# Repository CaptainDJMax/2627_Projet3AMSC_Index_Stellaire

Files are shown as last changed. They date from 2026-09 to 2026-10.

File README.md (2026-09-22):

## Project Description
The "Stellar Index" is an autonomous and aesthetic mechanical arm, designed to point in real time at a specific celestial object selected via a mobile or web app. Whether it's a planet, a star, the International Space Station (ISS), or a galaxy, the arm tracks the object continuously.

If the object goes below the horizon, the arm will point toward the ground. Designed with premium materials, it serves as both an educational science tool and an indoor kinetic art piece.

---

## Specifications & Technical Challenges

Here is the list of project requirements, along with recommended hardware choices and the technical challenges to anticipate.

### 1. Continuous 360° Celestial Tracking
**Description:** The arm must dynamically target a celestial object and compensate for Earth's rotation in real time, with no limits on its rotation.
- **Hardware:** A base motor for the Azimuth (horizontal) axis, a motor for the Elevation (vertical) axis, and a **slip ring** placed in the center of the rotation axis.
- **Difficulty:** Infinite rotation on the vertical axis requires a slip ring to pass the power and data cables from the base to the arm so they don't twist and snap.

### 2. Automatic Calibration via IMU and GNSS/GPS
**Description:** The user sets the object down, turns it on, and the system automatically determines its location, exact time, and spatial orientation (North, level) without manual input.
- **Hardware:** A GPS module (e.g., u-blox NEO-M8N for a quick lock) and a 9-axis Inertial Measurement Unit (IMU) with a built-in data fusion processor (e.g., BNO085 or BNO055).
- **Difficulty:** The IMU's magnetometer (compass) is extremely sensitive to ferrous metals and magnetic fields from the motors. The IMU must be placed as far away from the motors as possible (at the end of the arm), and a calibration algorithm is needed to compensate for the surrounding metal.

### 3. Easy to Transport (Foldable)
**Description:** The arm must fold down to fit into a custom carrying case.
- **Hardware:** Precision ball-bearing joints and **absolute magnetic encoders** (e.g., AS5600) on each critical axis.
- **Difficulty:** If the arm is folded while turned off, the system must know exactly what position it is in when turned back on. Absolute encoders are mandatory here because they remember the exact physical position, unlike standard relative encoders.

### 4. Elegant Design and Premium Materials (Brass)
**Description:** A high-end finish so it blends in as premium home decor.
- **Hardware:** Solid brass for the base, and anodized aluminum tubes (brass look) or brass-plated carbon fiber for the moving parts. Hidden screws.
- **Difficulty:** Brass is very dense and heavy. An arm made entirely of solid brass would require very powerful motors, which are bulky, noisy, and drain power quickly. You have to "cheat" on the moving parts by using lightweight materials that just look like brass.

### 5. Silent Operation
**Description:** The arm's movements must be virtually inaudible.
- **Hardware:** Ultra-silent motor drivers (e.g., Trinamic TMC2209 with StealthChop technology) for stepper motors, or FOC controllers (SimpleFOC) for brushless motors. Vibration dampers between the motors and the frame.
- **Difficulty:** Acoustically isolating the mechanical transmission (gears or belts). Neoprene timing belts are generally much quieter than metal gears.

### 6. Power Supply: Battery and Mains (10-hour battery life)
**Description:** Dual operation, featuring a custom built-in battery.
- **Hardware:** A Lithium-Ion cell pack (e.g., high-capacity 18650 or 21700 cells), a BMS (Battery Management System) board for safe charging/discharging, and a circuit that automatically switches between battery and wall power.
- **Difficulty:** Sizing the battery. When motors hold a position, they constantly drain energy to fight gravity. The arm must be physically balanced (by adding discreet counterweights) so the motors have to do as little work as possible.

### 7. Interface and Control
**Description:** A premium physical ON/OFF switch. The main control interface is a connected app via an API.
- **Hardware:** An **ESP32** microcontroller (which natively includes WiFi and Bluetooth BLE), and a metal toggle switch or capacitive push button integrated into the base design.
- **Difficulty:** Writing the software backend on the ESP32 so it can host a local API (an embedded web server) or seamlessly connect to the home WiFi using the user's phone Bluetooth.

### 8. Extended Offline Operation (72 hours)
**Description:** The arm must be able to track a target for 72 hours without an internet connection.
- **Hardware:** A high-precision, temperature-compensated **RTC (Real-Time Clock)** module (e.g., DS3231) with its own backup coin battery (CR2032).
- **Difficulty:** Time drift. Without the internet to resync the clock, a standard microcontroller loses several seconds a day. In astronomy, being off by just a few seconds completely ruins the pointing accuracy, making a dedicated RTC module absolutely necessary.

### 9. Interchangeable Tips
**Description:** The end of the arm can hold different attachments, like a "mechanical finger" or a laser pointer.
- **Hardware:** A quick-release connector (neodymium magnets with an alignment slot or a bayonet mount), and **Pogo Pins** (spring-loaded contacts) to send electricity to the laser module.
- **Difficulty:** Sending power to the laser tip without any visible wires, and making sure the tip always centers perfectly on the axis every time it gets swapped out.

### 10. Closed-Loop Control
**Description:** The system automatically corrects its own position errors (like if it gets bumped or misses a step).
- **Hardware:** High-resolution rotary encoders (e.g., AS5048A with 14-bit resolution) attached directly to the motor shafts.
- **Difficulty:** Software integration. You need to write a PID (Proportional, Integral, Derivative) controller into the code. This allows the microcontroller to compare where the arm *should* be with where the encoder says it *actually* is thousands of times per second, correcting the movement smoothly without making the arm shake.

---
<div align="center">
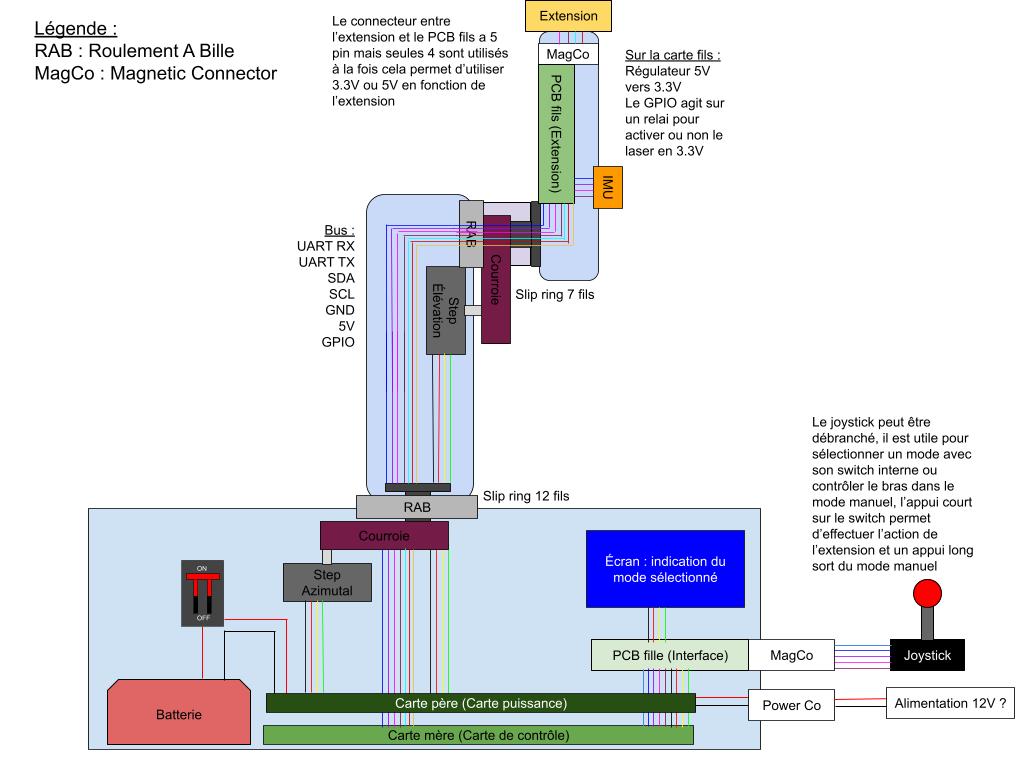
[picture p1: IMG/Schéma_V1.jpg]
Schéma de la V1
  
</div>

## Basic Electronic Stack (Summary)
* **Brain:** ESP32
* **Time & Space:** u-blox GPS, BNO085 IMU, DS3231 RTC
* **Movement:** Motors + Trinamic TMC2209 Drivers + Slip Ring
* **Position Sensors:** Absolute magnetic encoders (AS5600 / AS5048A)

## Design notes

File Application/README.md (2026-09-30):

# Index Stellaire - Application

Application web/mobile responsive (Django) permettant de piloter et suivre en temps réel le bras robotique **Index Stellaire**, un instrument pointant automatiquement vers des objets célestes (étoiles, planètes, ISS, ou toute direction/position arbitraire).

> Ce document décrit la **vision globale** de l'application. Les détails techniques d'implémentation (modèles de données, endpoints API, protocole BLE) seront traités dans un document séparé.

---

## Objectif

Permettre à l'utilisateur de :
- Visualiser le ciel et sélectionner un astre à pointer
- Suivre en continu un objet céleste (y compris rapide, comme l'ISS)
- Découvrir les événements observables à l'œil nu depuis sa position
- Contrôler l'appareil physique (Index Stellaire) via le serveur, en WiFi ou en partage de connexion 4G/5G (le Bluetooth n'est qu'un mode de secours local)
- Consulter l'état de l'appareil (batterie, position, dernière synchronisation) même sans lien temps réel permanent

---

## Fonctionnalités principales

### Carte du ciel interactive
- Visualisation du ciel en temps réel (calcul des positions via Skyfield côté serveur)
- Sélection d'un astre par clic ou recherche par nom
- Bouton **Pointer** / **Arrêter** pour déclencher ou stopper le suivi
- Position de repos ("parking") définie pour l'appareil quand rien n'est ciblé

### Événements à l'œil nu
- Liste des événements visibles **ce soir, depuis la position réelle de l'utilisateur** (pas un calendrier générique) : conjonctions, essaims de météores, passages ISS, etc.
- Notification push quand un événement approche
- Bouton pour pointer directement l'appareil vers l'événement sélectionné

### Recherche & planification
- Recherche libre d'un objet (planète, étoile, ISS, ou saisie manuelle de coordonnées RA/Dec pour un usage avancé)
- Programmation d'une cible à une heure donnée ("suivre l'ISS à 21h47")
- File d'attente de plusieurs cibles enchaînées dans la soirée

### Mode "cible personnalisée"
- Pointer une position arbitraire (coordonnées GPS d'un lieu, par exemple), y compris à travers le sol si l'objet/lieu est sous l'horizon, exploite la structure mécanique à liberté de mouvement complète de l'appareil

### Journal d'observation
- Historique des cibles pointées/observées
- Possibilité d'ajouter une note ou une photo prise au même moment

### Tableau de bord de l'appareil
- Batterie restante
- Cible actuellement suivie
- Statut GPS (fix ou non)
- Dernière synchronisation RTC
- Statut connecté / hors ligne, avec horodatage de la dernière donnée reçue (pas de fausse impression de temps réel permanent)

---

## Deux modes d'interface

L'application fonctionne même **sans appareil connecté** :

| Sans connexion à l'appareil | Avec connexion à l'appareil |
|---|---|
| Carte du ciel, recherche, événements, planification, historique | Pointer maintenant, calibration, statut batterie/position en direct |

Les actions nécessitant l'appareil sont désactivées (ou remplacées par un bouton "Connecter l'appareil") tant qu'aucune liaison n'est établie. Ça permet de développer/démontrer toute la partie logicielle indépendamment de l'avancement du matériel.

---

## Communication Application ↔ Appareil

### Architecture générale
- **Django** héberge la logique métier (calcul astro, événements, planification) sur un serveur. Pas de comptes utilisateurs au départ : l'accès se fait avec un code de session.
- **Déploiement en deux temps** :
  - **Mode local (maintenant)** : le téléphone, l'ESP32 et le serveur (Raspberry Pi) sont sur le même WiFi. Fonctionne uniquement à portée de ce WiFi.
  - **Mode distant (plus tard)** : le serveur est rendu accessible depuis internet via un tunnel, et l'ESP32 s'y connecte par le partage de connexion 4G/5G du téléphone.
- **ESP32** communique avec Django en HTTP/HTTPS, que ce soit sur le WiFi domestique ou via le partage de connexion 4G/5G du téléphone en extérieur, même flux dans les deux cas
- Polling léger et espacé (l'ESP32 récupère sa consigne et remonte un statut à intervalle régulier), pas de connexion permanente nécessaire
- **Répartition des rôles** : l'ESP32 gère la communication réseau ; le STM32 (relié par UART) fait les calculs de suivi et pilote les moteurs. L'application envoie une **cible** (un astre ou des coordonnées), pas des angles : c'est l'appareil qui calcule.
- **Bluetooth (secours)** : mode local optionnel pour pointer sans aucun réseau, à côté de l'appareil. Uniquement sur Android/Chrome (Web Bluetooth n'existe pas sur iPhone). Ce n'est pas le chemin principal.

### Cas particulier : suivi de l'ISS
L'ISS est un objet proche et rapide (contrairement aux étoiles, à distance infinie) : sa position nécessite une propagation orbitale (SGP4) à partir de données orbitales (TLE) fraîches.
- Avant un passage programmé, le serveur fournit à l'appareil un TLE à jour (l'ESP32 le relaie au STM32)
- Le suivi pendant le passage se fait ensuite **en calcul local** sur le STM32, sans dépendre d'une connexion active pendant les quelques minutes du survol

### Fonctionnement autonome (48h hors-ligne)
L'appareil ne dépend pas du réseau pour suivre une cible : son GPS embarqué, sa RTC et des éphémérides pré-chargées permettent un suivi continu jusqu'à 48h sans connexion (pour les satellites, le suivi autonome n'a de sens que peu après une mise à jour des TLE). Le réseau ne sert qu'à envoyer une consigne ponctuelle et récupérer un statut de temps en temps.

---

## Connexion de l'appareil

1. **Nouveau lieu / premier démarrage** : si l'ESP32 ne reconnaît aucun réseau WiFi enregistré, il crée son propre WiFi temporaire (par exemple `IndexStellaire-Setup`)
2. **Configuration du WiFi** : le téléphone s'y connecte, une page de configuration (servie par l'ESP32 lui-même) permet de choisir le réseau WiFi, la maison ou le partage de connexion du téléphone, et de saisir son mot de passe. Fonctionne sur iPhone comme sur Android, sans Bluetooth.
3. **Connexion à l'appli** : l'ESP32 affiche un code sur son écran, que l'utilisateur saisit dans l'appli pour se connecter
4. **Utilisations suivantes** : l'appareil se reconnaît tout seul au dernier réseau connu, plus besoin de reconfigurer ni de ressaisir le WiFi

### Gestion de la prise de contrôle
- Plusieurs personnes peuvent se connecter à l'appareil avec le code, mais une seule le contrôle à la fois
- Un bouton **"Reprendre la main"** permet de prendre le contrôle à la place de la personne qui l'a ; le dernier objet pointé reste visible et peut être changé
- Un appareil déjà appairé rejette toute nouvelle tentative d'appairage tant qu'il n'a pas été explicitement réinitialisé (action physique sur l'appareil)

---

## Stack technique (prévisionnelle)

- **Backend** : Django (+ Django REST Framework pour l'API)
- **Calcul astro** : Skyfield
- **Frontend** : responsive, installable en PWA, carte du ciel en canvas avec d3-celestial
- **Firmware appareil** : ESP32 (WiFi, communication avec le serveur) + STM32 (contrôle temps réel, calcul de suivi, SGP4 embarqué pour l'ISS), liaison UART
- **Sécurité API** : authentification par token pour l'appareil, code de session pour les utilisateurs, HTTPS (surtout en mode distant)

---

## Statut

Document de vision globale, l'architecture technique détaillée (modèles de données Django, format des messages API, protocole BLE précis) sera définie dans un document séparé.

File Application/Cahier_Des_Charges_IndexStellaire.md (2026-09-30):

# Cahier des charges - Application Index Stellaire

> **Index Stellaire** : bras robotique à 2 axes (sphère armillaire) pointant en temps réel vers des astres. Ce document décrit **l'application logicielle** (web/PWA Django) et son **API**.

- **Version** : 0.2 

---

## 1. Objectif

Piloter et accompagner le bras Index Stellaire : choisir un astre, le faire pointer, découvrir ce qui est observable depuis sa position, et suivre l'état de l'appareil.

L'application fonctionne d'abord **en local sur le réseau wifi domestique** (mode 1), et pourra plus tard être rendue accessible **depuis n'importe où** via un serveur exposé sur internet (mode 2, voir §7). L'appareil, lui, reste **autonome jusqu'à 48 h** sans l'application.

## 2. Périmètre et priorités

Chaque fonctionnalité est étiquetée :

- **[MVP]** — première version qui fonctionne de bout en bout
- **[v2]** — amélioration prévue après le MVP
- **[Futur]** — envisagé, non planifié

**Objectif de la v1 : une application qui marche à peu près de bout en bout**, quitte à revenir la durcir ensuite. On garde en tête pendant la conception l'endroit où brancher l'authentification et l'accès distant, sans le finaliser tout de suite.

## 3. Acteurs et plateformes

| Acteur | Rôle |
|---|---|
| Utilisateur (observateur) | Consulte le ciel, choisit et pointe des astres, contrôle l'appareil |
| Appareil (ESP32 + STM32) | Interroge le serveur, exécute le pointage, remonte sa télémétrie |
| Serveur Django | Calcule les positions, sert la carte, expose l'API, relaie les commandes |

**Plateformes cibles** : navigateur web responsive, installable en **PWA** (icône sur l'écran d'accueil, plein écran). Points à intégrer :

- **Contrôle principal via le serveur en HTTP(S)** : fonctionne sur tous les téléphones (iPhone comme Android).
- **BLE (pointage local direct) = Android/Chrome uniquement.** Pas de Web Bluetooth sur iOS ni Firefox. C'est donc un mode secondaire, réservé au cas où il n'y a aucun réseau du tout.
- **Notifications push web** : nécessitent la PWA installée à l'écran d'accueil (iOS ≥ 16.4) et **HTTPS**.

## 4. Architecture logicielle

### 4.1 Projet Django, deux apps

- **`ciel`** : contenu et calculs astronomiques : catalogues, constellations, positions (Skyfield), événements, fiches objets.
- **`appareil`** : communication avec l'appareil : appairage, jetons, sessions de contrôle, file de commandes, télémétrie.

Un seul projet, une seule base, un seul serveur. Séparation logique uniquement.

### 4.2 Briques externes

| Besoin | Choix retenu | Rôle |
|---|---|---|
| Calcul astro serveur | **Skyfield** (Python) | RA/Dec, alt/az topocentrique, lever/coucher, satellites (SGP4) |
| Éphémérides planètes | **JPL DE421/DE440** (fichier `.bsp`, chargé par Skyfield) | Positions Soleil, Lune, planètes |
| TLE satellites (ISS…) | **Celestrak** | Éléments orbitaux pour SGP4 |
| Carte du ciel (navigateur) | **d3-celestial** (canvas) | Rendu interactif étoiles/constellations/DSO |
| Catalogue d'étoiles | Données de d3-celestial / base type HYG | Alimente la carte et la recherche |
| PWA / push | Service worker + Web Push (VAPID) | Installation + notifications |

### 4.3 Répartition des calculs (serveur ↔ STM32)

- **Serveur** : calcule la position des astres (alt/az pour la position et l'heure données) pour l'affichage et le pointage, et fournit à l'appareil de quoi suivre en autonomie (identifiant de cible + éphémérides / TLE nécessaires). Gère la carte et les fiches.
- **STM32** : refait et affine les calculs en temps réel pour le suivi fin, et **continue seul en cas de déconnexion** à partir de la dernière cible connue et de son **GPS embarqué** (position et heure), jusqu'à 48 h.
- **L'application envoie une cible** (astre à suivre ou coordonnées), **pas des angles bruts** : l'appareil reste maître du suivi (décision D1).

## 5. Fonctionnalités

### 5.1 Carte du ciel `ciel`

- **F1 [MVP]** Carte du ciel interactive en canvas, style soigné cohérent avec l'univers du projet (fond nocturne, étoiles par magnitude, lignes de constellations, Voie lactée).
- **F2 [MVP]** Affichage centré sur la **position GPS réelle** et l'heure courante.
- **F3 [MVP]** Sélection d'un objet par clic sur la carte → ouverture de sa fiche.
- **F4 [MVP]** Bouton **Pointer** / **Arrêter** depuis la carte ou la fiche.
- **F36 [MVP]** **Filtres d'affichage** : choisir les types d'objets visibles (étoiles seules, planètes, Lune/Soleil, satellites, ciel profond, comètes) en plus du seuil de magnitude. Les filtres s'appliquent aussi à la recherche.
- **F5 [v2]** Affichage/masquage des dessins artistiques de constellations (ex. Cancer, Capricorne).
- **F6 [Futur]** Mode boussole / réalité augmentée (capteurs du téléphone), **exclu du MVP**.

### 5.2 Objets pris en charge

- **F7 [MVP]** Étoiles (seuil de magnitude réglable), planètes, Lune, Soleil, ISS.
- **F8 [v2]** Autres satellites, comètes, objets Messier/NGC.
- **F9** *(Sans objet.)* Le laser est à **usage intérieur uniquement** (décision D3) ; aucun verrouillage Soleil n'est nécessaire au MVP. À revoir si un embout optique est un jour utilisé en extérieur.

### 5.3 Fiches objets

- **F10 [MVP]** Fiche par objet : nom, type, magnitude, coordonnées, visibilité ce soir (lever/coucher, hauteur max).
- **F11 [v2]** Contenu enrichi : description **issue de sources fiables**, mythologie, image **libre de droits**.
  - Règle transverse (D7) : chaque contenu ajouté (fiche, événement, image) est **recherché et vérifié à la source au moment de l'ajout**, avec sa source et sa licence notées.
  - Sources images à privilégier : NASA/ESA, Wikimedia Commons (licence vérifiée par image).

### 5.4 Recherche

- **F12 [MVP]** Recherche d'un objet par nom, avec accès direct à sa fiche et au pointage. Respecte les filtres (F36).

### 5.5 Événements à l'œil nu

- **F13 [v2]** Liste des **événements observables ce soir depuis la position réelle** : conjonctions, essaims de météores, passages ISS, phases de Lune, etc.
- **F14 [v2]** Événements **calculés en interne** avec Skyfield (D6). Si le serveur a accès à internet, une **source externe spécialisée et vérifiée** peut compléter la liste.
- **F15 [v2]** Chaque événement renvoie à l'objet concerné et permet de le pointer.
- **F16 [v2]** **Notifications** d'événements (via Web Push, PWA installée).

### 5.6 Pointage et contrôle de l'appareil `appareil`

- **F17 [MVP]** **Pointage simple** : l'utilisateur choisit un objet (ou une cible personnalisée), l'appareil pointe et suit. Un seul mode pour l'instant.
- **F18 [MVP]** **Cible personnalisée** : pointer des coordonnées arbitraires, y compris **sous l'horizon** (direction géométrique réelle à travers la Terre), choix fait depuis l'app.
- **F19 [MVP]** **Position de repos (parking)** quand aucune cible n'est active.
- **F20 [MVP]** L'app **ne gère pas les embouts** : elle envoie uniquement des ordres de pointage, et le firmware s'occupe de l'embout monté (y compris le changement de pin). Aucun impact côté app au MVP ; la détection de l'embout reste à définir côté matériel (voir P8).
- **F37 [MVP]** **Configuration wifi de l'appareil** : point d'accès temporaire au démarrage + page de configuration minimaliste servie par l'ESP32 (choix du réseau, mot de passe), voir §7.3.
- **F21 [v2]** Affichage de l'embout détecté (lecture seule) et, plus tard, contrôle (laser on/off, couleur).
- **F22 [v2]** Visite guidée / file d'observation enchaînant plusieurs objets, avec horaires.

### 5.7 Calibration

- **F23 [MVP]** Bouton **« Calibrer »** lançant la procédure (alignement au démarrage). Pas de joystick virtuel au MVP.
- **F24 [Futur]** Réglage fin manuel (joystick virtuel dans l'app), le joystick physique reste la voie matérielle.

### 5.8 État de l'appareil (page dédiée)

- **F25 [MVP]** Page **« État »** séparée : niveau de batterie, fix GPS, connecté/déconnecté, dernière synchronisation, dernière cible pointée.
- **F26 [v2]** Télémétrie détaillée : température drivers, angles encodeurs, précision estimée, erreurs.
- **F27 [Futur]** Mise à jour firmware OTA depuis l'app.

### 5.9 Sessions et multi-utilisateur

- **F28 [MVP]** **Plusieurs personnes peuvent se connecter à l'appareil** (via un **code de session**), mais **une seule contrôle à la fois**. Pas de comptes utilisateurs au départ (D2).
- **F29 [MVP]** Bouton **« Prendre le contrôle »** : reprend la main sur la session en cours.
- **F30 [MVP]** À la reprise, le nouvel utilisateur **voit le dernier objet pointé** et peut le changer.
- **F31 [MVP]** **Interface connectée/déconnectée** : boutons d'action grisés quand l'appareil est hors ligne.
- **F32 [MVP]** **Heartbeat** pour détecter l'état en ligne/hors ligne.

### 5.10 Mode autonome

- **F33 [MVP]** L'appareil **suit sa cible seul jusqu'à 48 h** sans réseau ni app, à partir de la dernière cible et de son GPS embarqué. Le STM32 doit embarquer les données nécessaires (éphémérides Soleil/Lune/planètes, catalogue d'étoiles) pour couvrir cette durée.
- **F34 [MVP]** Au-delà (jusqu'à ~72 h max), retour à un comportement normal / parking.
- **F35 [MVP]** À la reconnexion, l'app récupère l'état réel (dernière cible, batterie, position).

> **Limite connue** : pour étoiles, planètes et Lune, les calculs restent précis sur 48 h. Pour l'ISS et les satellites, les TLE se dégradent en quelques jours et l'objet passe vite : le suivi autonome n'a de sens que peu après une mise à jour des TLE.

## 6. API (celle que tu construis)

API REST servie par Django, consommée par l'app web **et** par l'ESP32. Esquisse à affiner :

**Côté appareil (ESP32 → serveur, polling HTTP/HTTPS)**
- `POST /api/device/heartbeat` — signale l'état (batterie, GPS, cible en cours) et récupère la prochaine commande.
- `GET  /api/device/command` — commande courante à exécuter (cible + éphémérides/TLE nécessaires au suivi autonome).
- `POST /api/device/telemetry` — remontée de télémétrie détaillée.

**Côté application (navigateur → serveur)**
- `GET  /api/sky/objects?lat=&lon=&t=` — objets visibles + positions alt/az (filtrables).
- `GET  /api/objects/{id}` — fiche objet.
- `GET  /api/search?q=` — recherche.
- `GET  /api/events?lat=&lon=&date=` — événements du soir.
- `POST /api/point` — demander le pointage d'une cible (objet ou coordonnées).
- `POST /api/stop` — arrêt / retour au parking.
- `POST /api/calibrate` — lancer la calibration.
- `POST /api/control/take` — prendre le contrôle (avec code de session).
- `GET  /api/device/status` — état pour la page « État ».

**Authentification** : jeton par appareil (ESP32) + code de session pour la prise de contrôle. Pas de comptes utilisateurs au départ (D2).

**Sources externes consommées** (ne sont pas ton API) : Celestrak (TLE), fichier éphémérides JPL (via Skyfield), catalogue d'étoiles, images/textes libres.

## 7. Contraintes techniques et modes de déploiement

### 7.1 Mode 1 - Local (maintenant, développement et tests)

Téléphone, ESP32 et serveur Django (Raspberry Pi) sont **tous sur le même réseau wifi** (ta box). Le téléphone accède au serveur via son adresse locale, l'ESP32 l'interroge sur ce même réseau. Fonctionne uniquement à portée de ce wifi. C'est le mode de départ.

### 7.2 Mode 2 - Distant (plus tard, usage en extérieur)

Le serveur est rendu accessible depuis internet via un **tunnel** (Cloudflare Tunnel, ou Tailscale), sans exposer directement la box.

- **Principe du tunnel** : le Raspberry Pi ouvre lui-même une connexion sortante permanente vers un service intermédiaire public (ex. Cloudflare). Cette connexion sortante n'est pas bloquée par la box. Le service fournit une adresse web publique ; les requêtes venues de l'extérieur transitent par ce « tuyau » jusqu'au Pi. La box n'a jamais à accepter de connexion entrante.
- Le téléphone accède alors au serveur en 4G ou sur n'importe quel wifi.
- L'ESP32 y accède via le **hotspot 4G du téléphone** : c'est le seul réseau qui suit l'utilisateur partout sans reconfiguration.

### 7.3 Configuration wifi de l'ESP32 depuis un autre endroit

Au démarrage, si l'ESP32 ne reconnaît aucun réseau enregistré, il **crée son propre point d'accès wifi temporaire** (ex. `IndexStellaire-Setup`).

1. Le téléphone se connecte à ce point d'accès comme à un routeur classique (via les réglages wifi du téléphone, pas via l'app).
2. Une **page de configuration minimaliste**, servie directement par l'ESP32 (pas par le serveur Django, il n'a pas encore internet à ce stade), s'ouvre automatiquement ou via une adresse fixe (ex. `192.168.4.1`).
3. Cette page liste les réseaux wifi détectés à proximité (+ option hotspot du téléphone), avec un champ mot de passe.
4. Une fois validé, l'ESP32 redémarre connecté à ce réseau et devient joignable normalement par le serveur.

**Deux interfaces distinctes** : la page de configuration (servie par l'ESP32, minimaliste, utilisée une fois par nouveau réseau) et l'app Index Stellaire (servie par le serveur Django, usage courant). Elles ne partagent ni code ni hébergement. Ce mécanisme fonctionne sur Android **et** iPhone (pas de Bluetooth requis).

### 7.4 Autres contraintes

- **C1** HTTPS obligatoire (push web, service worker, géolocalisation, sécurité API), pertinent surtout en mode 2.
- **C3** Communication appareil : **HTTP(S) polling** (pas de WebSocket permanent).
- **C4** BLE (pointage local direct) : mode Android/Chrome uniquement, secondaire, indépendant de la configuration wifi (7.3).
- **C5** App conçue en **PWA** (manifest + service worker) dès le départ.

## 8. Exigences non fonctionnelles

- **N1 Latence** : après calibration, un ordre de pointage doit aboutir en **~20–30 s** maximum.
- **N2 Autonomie** : suivi seul **48 h** (jusqu'à 72 h), puis retour normal.
- **N3 Précision** : niveau télescope (arcminute), dépend surtout du matériel/firmware ; l'app envoie des cibles cohérentes avec cet objectif.
- **N4 Langue** : **français**.
- **N5 Thème** : **mode nocturne** (fond sombre, idéalement variante rouge pour préserver la vision d'obscurité).
- **N6 Robustesse hors-ligne** : l'app gère proprement l'appareil déconnecté (état grisé, dernière donnée connue).

## 9. Ordre de développement conseillé

1. Squelette Django (`ciel`, `appareil`) + PWA + thème nocturne.
2. Carte du ciel (d3-celestial) + positions Skyfield + filtres + fiches minimales (F1–F4, F36, F7, F10, F12).
3. **API + appareil simulé** (mock) : pointer/arrêter/état sans matériel (F17–F19, F25, F28–F32).
4. Branchement de l'appareil réel + configuration wifi + mode autonome (F37, F33–F35).
5. Enrichissement : événements, notifications, fiches enrichies, file d'observation (F13–F16, F11, F22).
6. Durcissement : accès distant sécurisé (mode 2, tunnel), sécurité du code de session, télémétrie détaillée.

> Développer d'abord contre un **appareil simulé** permet de finir une app fonctionnelle même sans le matériel prêt.

## 10. Décisions matérielles reprises (contexte)

Pour cohérence app/matériel, rappel de ce qui est déjà acté côté hardware : structure sphère armillaire, 2 axes (azimut + élévation), moteurs pas à pas + slip ring (rotation continue azimut), ESP32 + STM32 (liaison UART).

*(Le reste du matériel, capteurs, drivers, alimentation, sera précisé plus tard et n'est pas figé ici.)*

## 11. Décisions prises et points ouverts

### Décisions prises

- **D1 Cible plutôt qu'angles** : l'app envoie une **cible** (objet ou coordonnées) ; le STM32 fait les calculs de suivi.
- **D2 Utilisateurs** : mono-utilisateur au départ (Maui), sans comptes. D'autres personnes utilisent leur téléphone en se connectant avec le **code de session** (F28).
- **D3 Laser** : usage **en intérieur uniquement**. Pas de verrouillage Soleil au MVP (F9 sans objet).
- **D4 Carte** : **d3-celestial** (canvas).
- **D5 Autonomie** : **48 h** de suivi autonome, l'appareil calculant seul avec son **propre GPS**.
- **D6 Événements** : **calculés en interne** (Skyfield) ; complétés par une source externe vérifiée si internet est disponible (v2).
- **D7 Sources** : chaque contenu ajouté (fiche, événement, image) est **recherché et vérifié à la source au moment de l'ajout**, source et licence notées.
- **D8 Déploiement** : **mode 1 (local, même wifi)** maintenant ; **mode 2 (serveur exposé via tunnel + hotspot 4G)** plus tard.
- **D9 Configuration wifi** : via **point d'accès temporaire de l'ESP32** et page de configuration servie par l'appareil (pas de Bluetooth requis).

### Points encore ouverts

- **P8** Détection de l'embout côté matériel (comment l'appareil identifie l'embout monté), nécessaire seulement pour F21.
- Comportement exact du **code de session** : durée de validité, régénération, nombre d'essais (surtout en mode 2, serveur exposé).
- Protection de l'accès quand le serveur sera exposé hors du domicile (mode 2).
- Comportement précis au-delà de 48 h (F34).

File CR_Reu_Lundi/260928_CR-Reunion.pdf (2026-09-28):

### État d’avancement:

Mécanique
pas encore commencé
Firmware
commencement de test, slip ring (test des interférences), stepper. Application
Début de recherche, en comparant différente application déjà existante Electronique
Finition de recheche des composant pour lancer le début des PCB

### GANTT avancement :

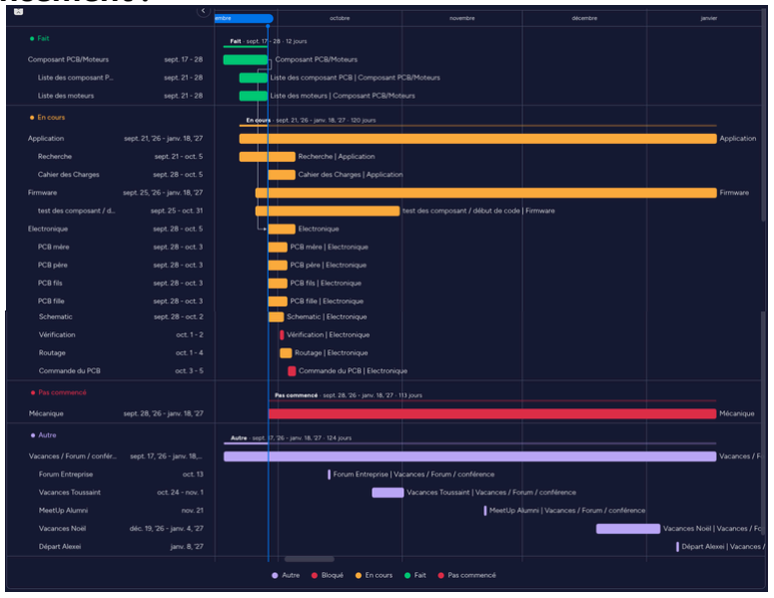
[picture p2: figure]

### Avancement semaine :

Mécanique
Commencement du OnShape
Firmware
Continuer la partie code sur des composant similaire en attendant les composant réel commandé suite à une comande effective mardi au plus tard
Application
Création d’un cahier des charges afin d’avoir une ligne directrice de l’application (validation en interne) (deadline 5 Oct.)
Electronique (Deadline 5 Oct)
Lancement des PCB, Mère (Adrien), Père/Fils (Alexeï), Fille (Laura), Objectif finir le schématic le 1er Oct. afin de faire une vérification par des profs et en interne. Puis finir le routage d’ici le 5 Oct. afin de lancer la commande à JLCPCB
Le plus important de la semaine est de finir les PCB afin de continuer le
projet sur de bon timing
CR Réunion | 28/09/2026

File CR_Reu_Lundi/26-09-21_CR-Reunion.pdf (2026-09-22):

### Point d’avancement :

Répartition des rôles effectué, détails : Chef; Équipe Composant PCB/Moteurs : ALL
Mécanique : Alexei; Émilie, Laura Electronique : Adrien; Alexei, Laura
Firmware : Émilie; Maxime, Alexei
Application : Maxime; Adrien

Gantt de la semaine, cf GitHub projet pour une version plus lisible

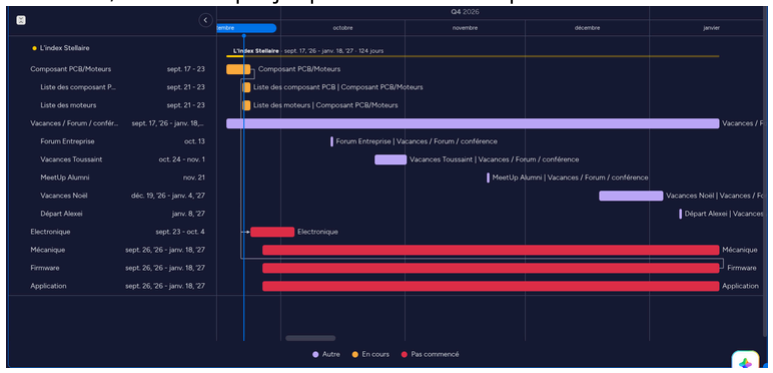
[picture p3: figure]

### Suite de la Semaine :

Objectifs :
Finir la liste des composants, deadline fixé à Mercredi 23 Septembre
Nous souhaitons fixer tout les composant dont nous avons besoins comme ça, cela va nous permettre de vérifier à 5 les calcule futur dont on aura besoins pour la création des PCB, l’idée c’est de tout valider avant la créations des PCB pour éviter un
maximum d’erreur par la suite.
tchekliste :
lien Composant / pin alloué microcontroleurs calcul, des résistances, des sécuritées disponibilité sur JLCPCB
Lundi beaucoups de questions on était posé sur la faisabilitée du projet niveau batterie (switch secteur / Batterie) et aussi sur les moteurs (brushless / stepper). Nous avons besoins d’en parler a M. Bares pour être fixé, discution prévu mardi midi

A partir de mercredi (et ou avant, si on a fini de fixer les composants avant) nous attaquons les PCB Père, Mère, Fils, Fille (Puissance, Cerveau, Magnétomètre, Interface) Deadline Dimanche 4 Octobre

En parallèles Maxime a commencé l’application avec un croquis minute, il se renseigne aussi à quoi ressemble les applications sur le marcher Deadline avant fin de projet (pas assez de date pour le moment pour être précis)

CR Réunion | 21/09/2026

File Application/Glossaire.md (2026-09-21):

# Glossaire

**BLE** = Bluetooth Low Energy, une variante du Bluetooth classique optimisée pour consommer très peu d'énergie. C'est ce qu'on utilise pour l'appairage/contrôle de proximité entre le téléphone et l'appareil.

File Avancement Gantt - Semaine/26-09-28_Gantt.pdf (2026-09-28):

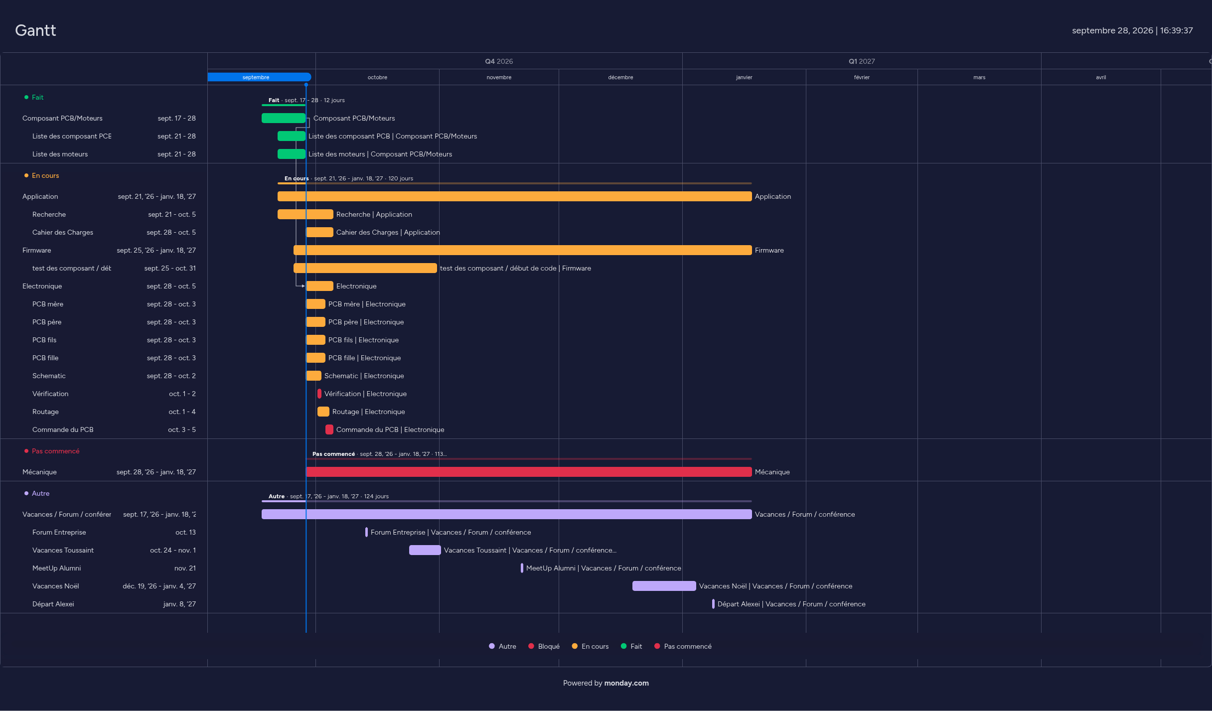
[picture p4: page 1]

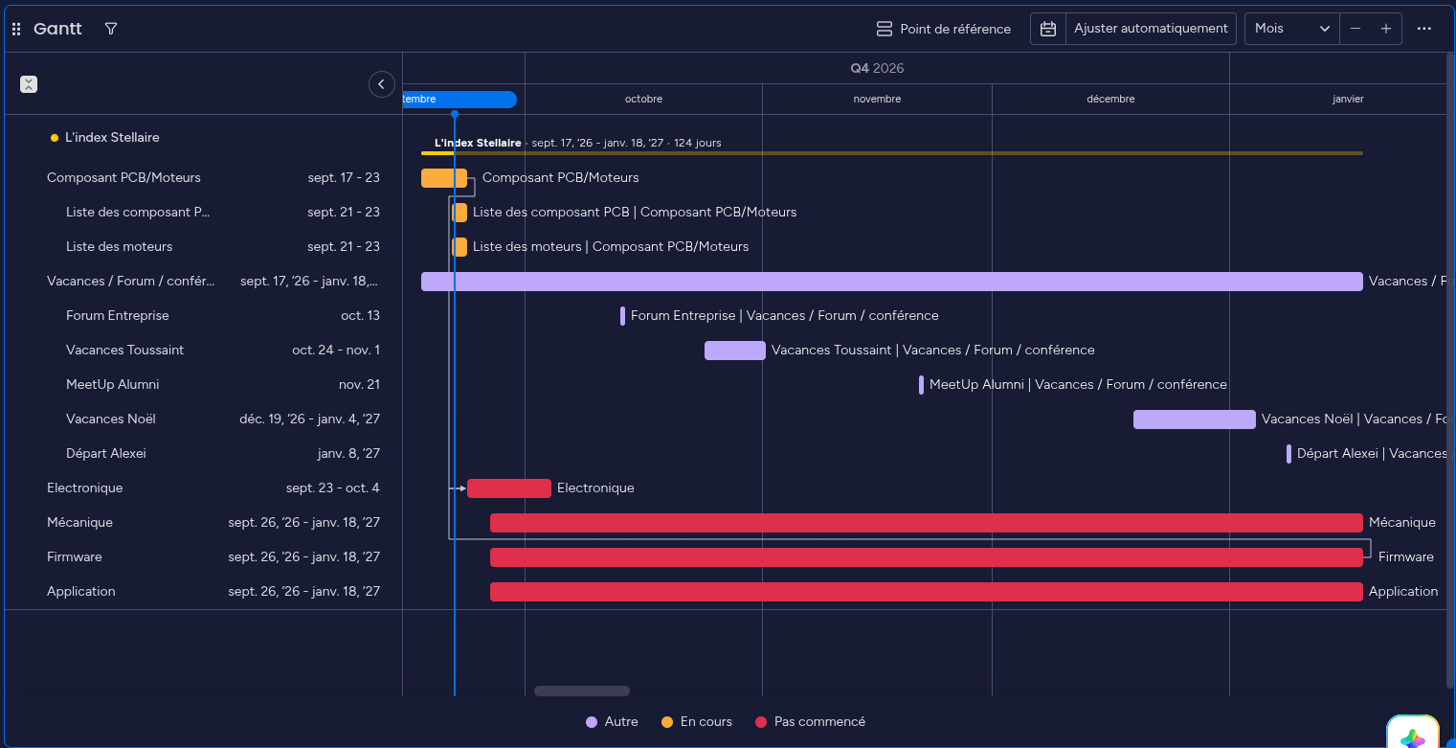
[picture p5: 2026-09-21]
Avancement Gantt - Semaine/26-09-21_Gantt.png

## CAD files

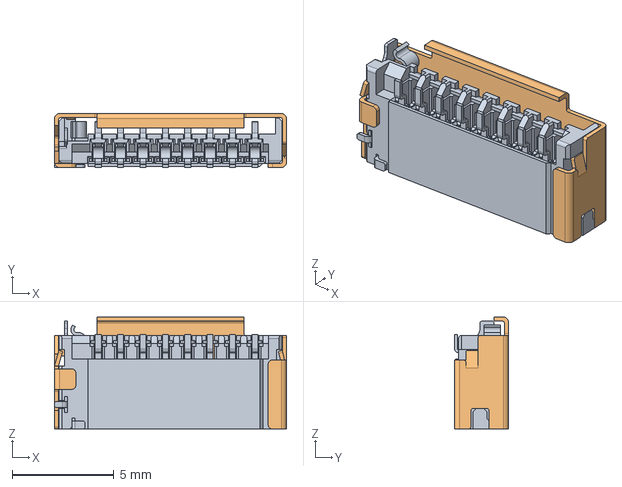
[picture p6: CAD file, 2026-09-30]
Hardware/PCB/Custom_library/Lecteur-SD_473092651/473092651.stp
11.4 x 2.65 x 5.50 mm

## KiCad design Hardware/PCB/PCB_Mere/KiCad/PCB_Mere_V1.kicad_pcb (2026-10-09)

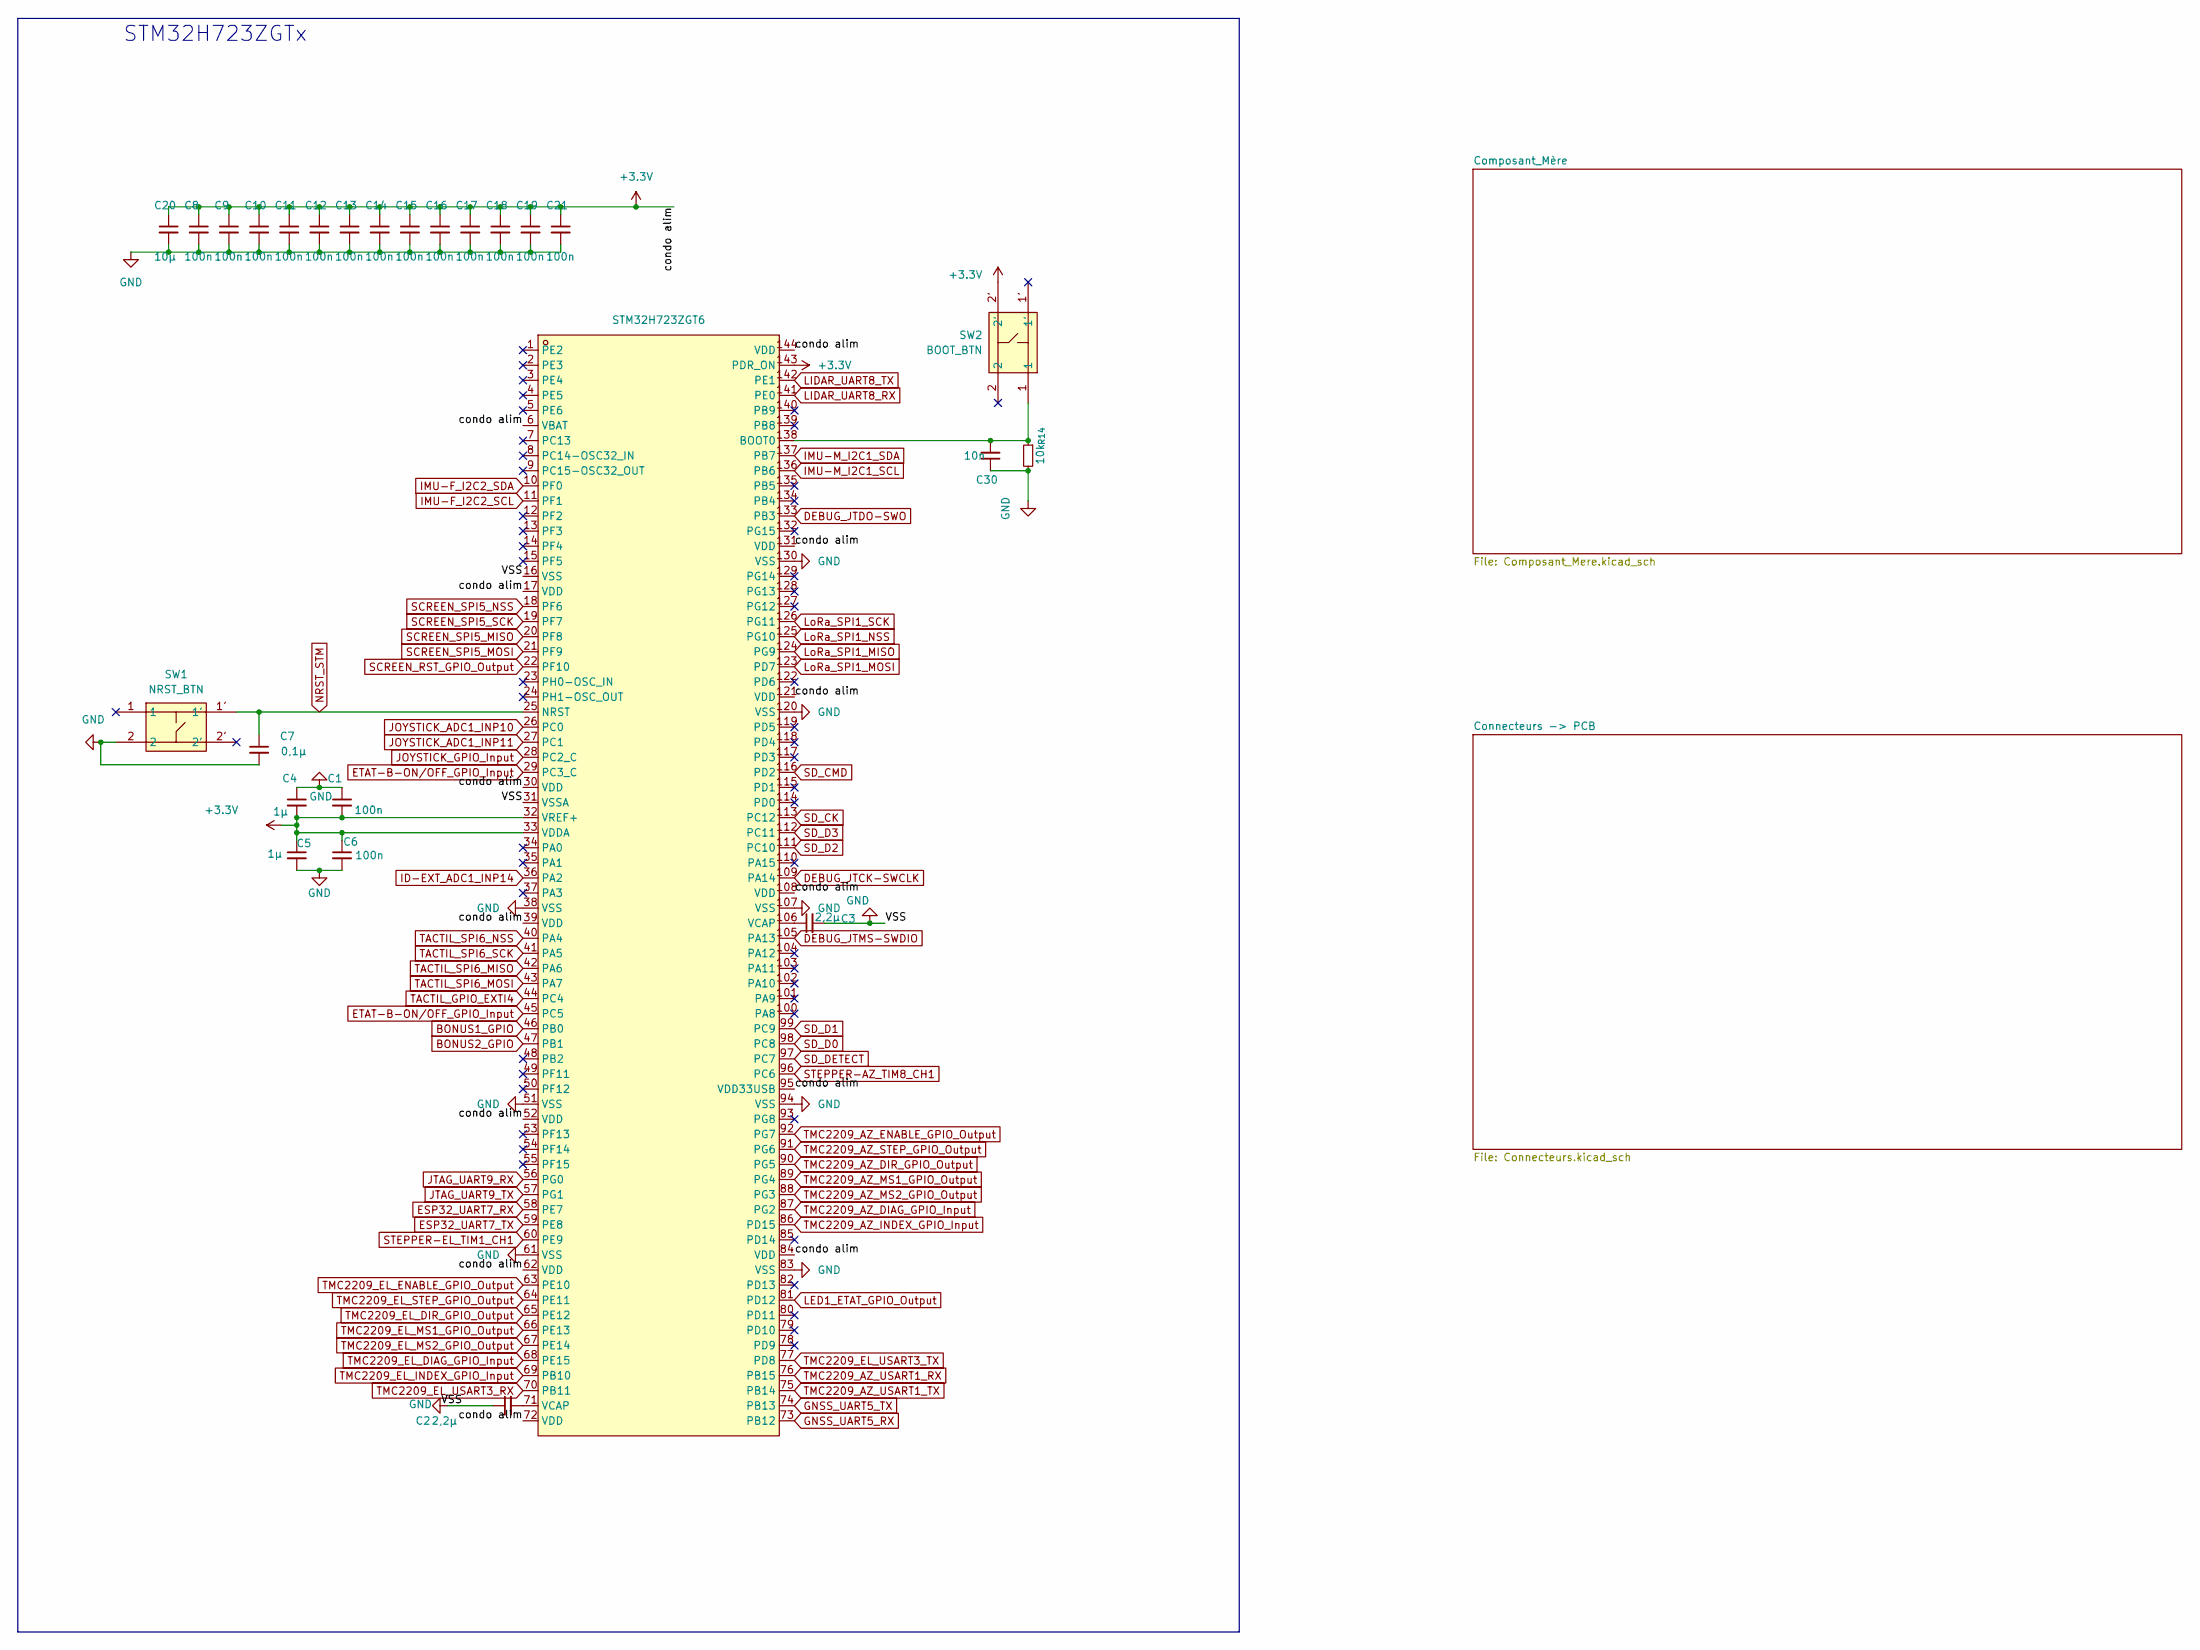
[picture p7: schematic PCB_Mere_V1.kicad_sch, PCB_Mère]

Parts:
C1, C6, C8, C9, C10, C11, C12, C13, C14, C15, C16, C17, C18, C19, C21: 100n; C_0201_0603Metric; LCSC Part C49062
C2, C3: 2,2µ; C_0201_0603Metric; LCSC Part C307418
C4, C5: 1µ; C_0201_0603Metric; LCSC Part C52923
C7: 0,1µ; C_0201_0603Metric; LCSC Part C49062
C20: 10µ; C_0201_0603Metric; LCSC Part C19702
C30: 10n; C_0402_1005Metric; LCSC Part C19702
R14: 10k; R_0201_0603Metric; LCSC Part C100126
SW1: NRST_BTN; KEY-SMD_4P-L3.5-W2.9-P1.48-LS4.3-TL; MPN EVPAA202K; LCSC Part C79147
SW2: BOOT_BTN; KEY-SMD_4P-L3.5-W2.9-P1.48-LS4.3-TL; MPN EVPAA202K; LCSC Part C79147
U1: STM32H723ZGT6; LQFP-144_L20.0-W20.0-P0.50-LS22.0-BL; MPN STM32H723ZGT6; LCSC Part C730146

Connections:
BONUS1_GPIO: U1.46 (PB0); also elsewhere on the board
BONUS2_GPIO: U1.47 (PB1); also elsewhere on the board
DEBUG_JTCK-SWCLK: U1.109 (PA14); also elsewhere on the board
DEBUG_JTDO-SWO: U1.133 (PB3); also elsewhere on the board
DEBUG_JTMS-SWDIO: U1.105 (PA13); also elsewhere on the board
ESP32_UART7_RX: U1.58 (PE7); also elsewhere on the board
ESP32_UART7_TX: U1.59 (PE8); also elsewhere on the board
ETAT-B-ON/OFF_GPIO_Input: U1.29 (PC3_C), U1.45 (PC5); also elsewhere on the board
GNSS_UART5_RX: U1.73 (PB12); also elsewhere on the board
GNSS_UART5_TX: U1.74 (PB13); also elsewhere on the board
ID-EXT_ADC1_INP14: U1.36 (PA2); also elsewhere on the board
IMU-F_I2C2_SCL: U1.11 (PF1); also elsewhere on the board
IMU-F_I2C2_SDA: U1.10 (PF0); also elsewhere on the board
IMU-M_I2C1_SCL: U1.136 (PB6); also elsewhere on the board
IMU-M_I2C1_SDA: U1.137 (PB7); also elsewhere on the board
JOYSTICK_ADC1_INP10: U1.26 (PC0); also elsewhere on the board
JOYSTICK_ADC1_INP11: U1.27 (PC1); also elsewhere on the board
JOYSTICK_GPIO_Input: U1.28 (PC2_C); also elsewhere on the board
JTAG_UART9_RX: U1.56 (PG0); also elsewhere on the board
JTAG_UART9_TX: U1.57 (PG1); also elsewhere on the board
LED1_ETAT_GPIO_Output: U1.81 (PD12); also elsewhere on the board
LIDAR_UART8_RX: U1.141 (PE0); also elsewhere on the board
LIDAR_UART8_TX: U1.142 (PE1); also elsewhere on the board
LoRa_SPI1_MISO: U1.124 (PG9); also elsewhere on the board
LoRa_SPI1_MOSI: U1.123 (PD7); also elsewhere on the board
LoRa_SPI1_NSS: U1.125 (PG10); also elsewhere on the board
LoRa_SPI1_SCK: U1.126 (PG11); also elsewhere on the board
NRST_STM: C7.1, SW1.1', U1.25 (NRST); also elsewhere on the board
unnamed: C2.2, U1.71 (VCAP)
unnamed: C3.1, U1.106 (VCAP)
unnamed: C30.2, R14.1, SW2.1, U1.138 (BOOT0)
SCREEN_RST_GPIO_Output: U1.22 (PF10); also elsewhere on the board
SCREEN_SPI5_MISO: U1.20 (PF8); also elsewhere on the board
SCREEN_SPI5_MOSI: U1.21 (PF9); also elsewhere on the board
SCREEN_SPI5_NSS: U1.18 (PF6); also elsewhere on the board
SCREEN_SPI5_SCK: U1.19 (PF7); also elsewhere on the board
SD_CK: U1.113 (PC12); also elsewhere on the board
SD_CMD: U1.116 (PD2); also elsewhere on the board
SD_D0: U1.98 (PC8); also elsewhere on the board
SD_D1: U1.99 (PC9); also elsewhere on the board
SD_D2: U1.111 (PC10); also elsewhere on the board
SD_D3: U1.112 (PC11); also elsewhere on the board
SD_DETECT: U1.97 (PC7); also elsewhere on the board
STEPPER-AZ_TIM8_CH1: U1.96 (PC6); also elsewhere on the board
STEPPER-EL_TIM1_CH1: U1.60 (PE9); also elsewhere on the board
TACTIL_GPIO_EXTI4: U1.44 (PC4); also elsewhere on the board
TACTIL_SPI6_MISO: U1.42 (PA6); also elsewhere on the board
TACTIL_SPI6_MOSI: U1.43 (PA7); also elsewhere on the board
TACTIL_SPI6_NSS: U1.40 (PA4); also elsewhere on the board
TACTIL_SPI6_SCK: U1.41 (PA5); also elsewhere on the board
TMC2209_AZ_DIAG_GPIO_Input: U1.87 (PG2); also elsewhere on the board
TMC2209_AZ_DIR_GPIO_Output: U1.90 (PG5); also elsewhere on the board
TMC2209_AZ_ENABLE_GPIO_Output: U1.92 (PG7); also elsewhere on the board
TMC2209_AZ_INDEX_GPIO_Input: U1.86 (PD15); also elsewhere on the board
TMC2209_AZ_MS1_GPIO_Output: U1.89 (PG4); also elsewhere on the board
TMC2209_AZ_MS2_GPIO_Output: U1.88 (PG3); also elsewhere on the board
TMC2209_AZ_STEP_GPIO_Output: U1.91 (PG6); also elsewhere on the board
TMC2209_AZ_USART1_RX: U1.76 (PB15); also elsewhere on the board
TMC2209_AZ_USART1_TX: U1.75 (PB14); also elsewhere on the board
TMC2209_EL_DIAG_GPIO_Input: U1.68 (PE15); also elsewhere on the board
TMC2209_EL_DIR_GPIO_Output: U1.65 (PE12); also elsewhere on the board
TMC2209_EL_ENABLE_GPIO_Output: U1.63 (PE10); also elsewhere on the board
TMC2209_EL_INDEX_GPIO_Input: U1.69 (PB10); also elsewhere on the board
TMC2209_EL_MS1_GPIO_Output: U1.66 (PE13); also elsewhere on the board
TMC2209_EL_MS2_GPIO_Output: U1.67 (PE14); also elsewhere on the board
TMC2209_EL_STEP_GPIO_Output: U1.64 (PE11); also elsewhere on the board
TMC2209_EL_USART3_RX: U1.70 (PB11); also elsewhere on the board
TMC2209_EL_USART3_TX: U1.77 (PD8); also elsewhere on the board

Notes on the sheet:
STM32H723ZGTx

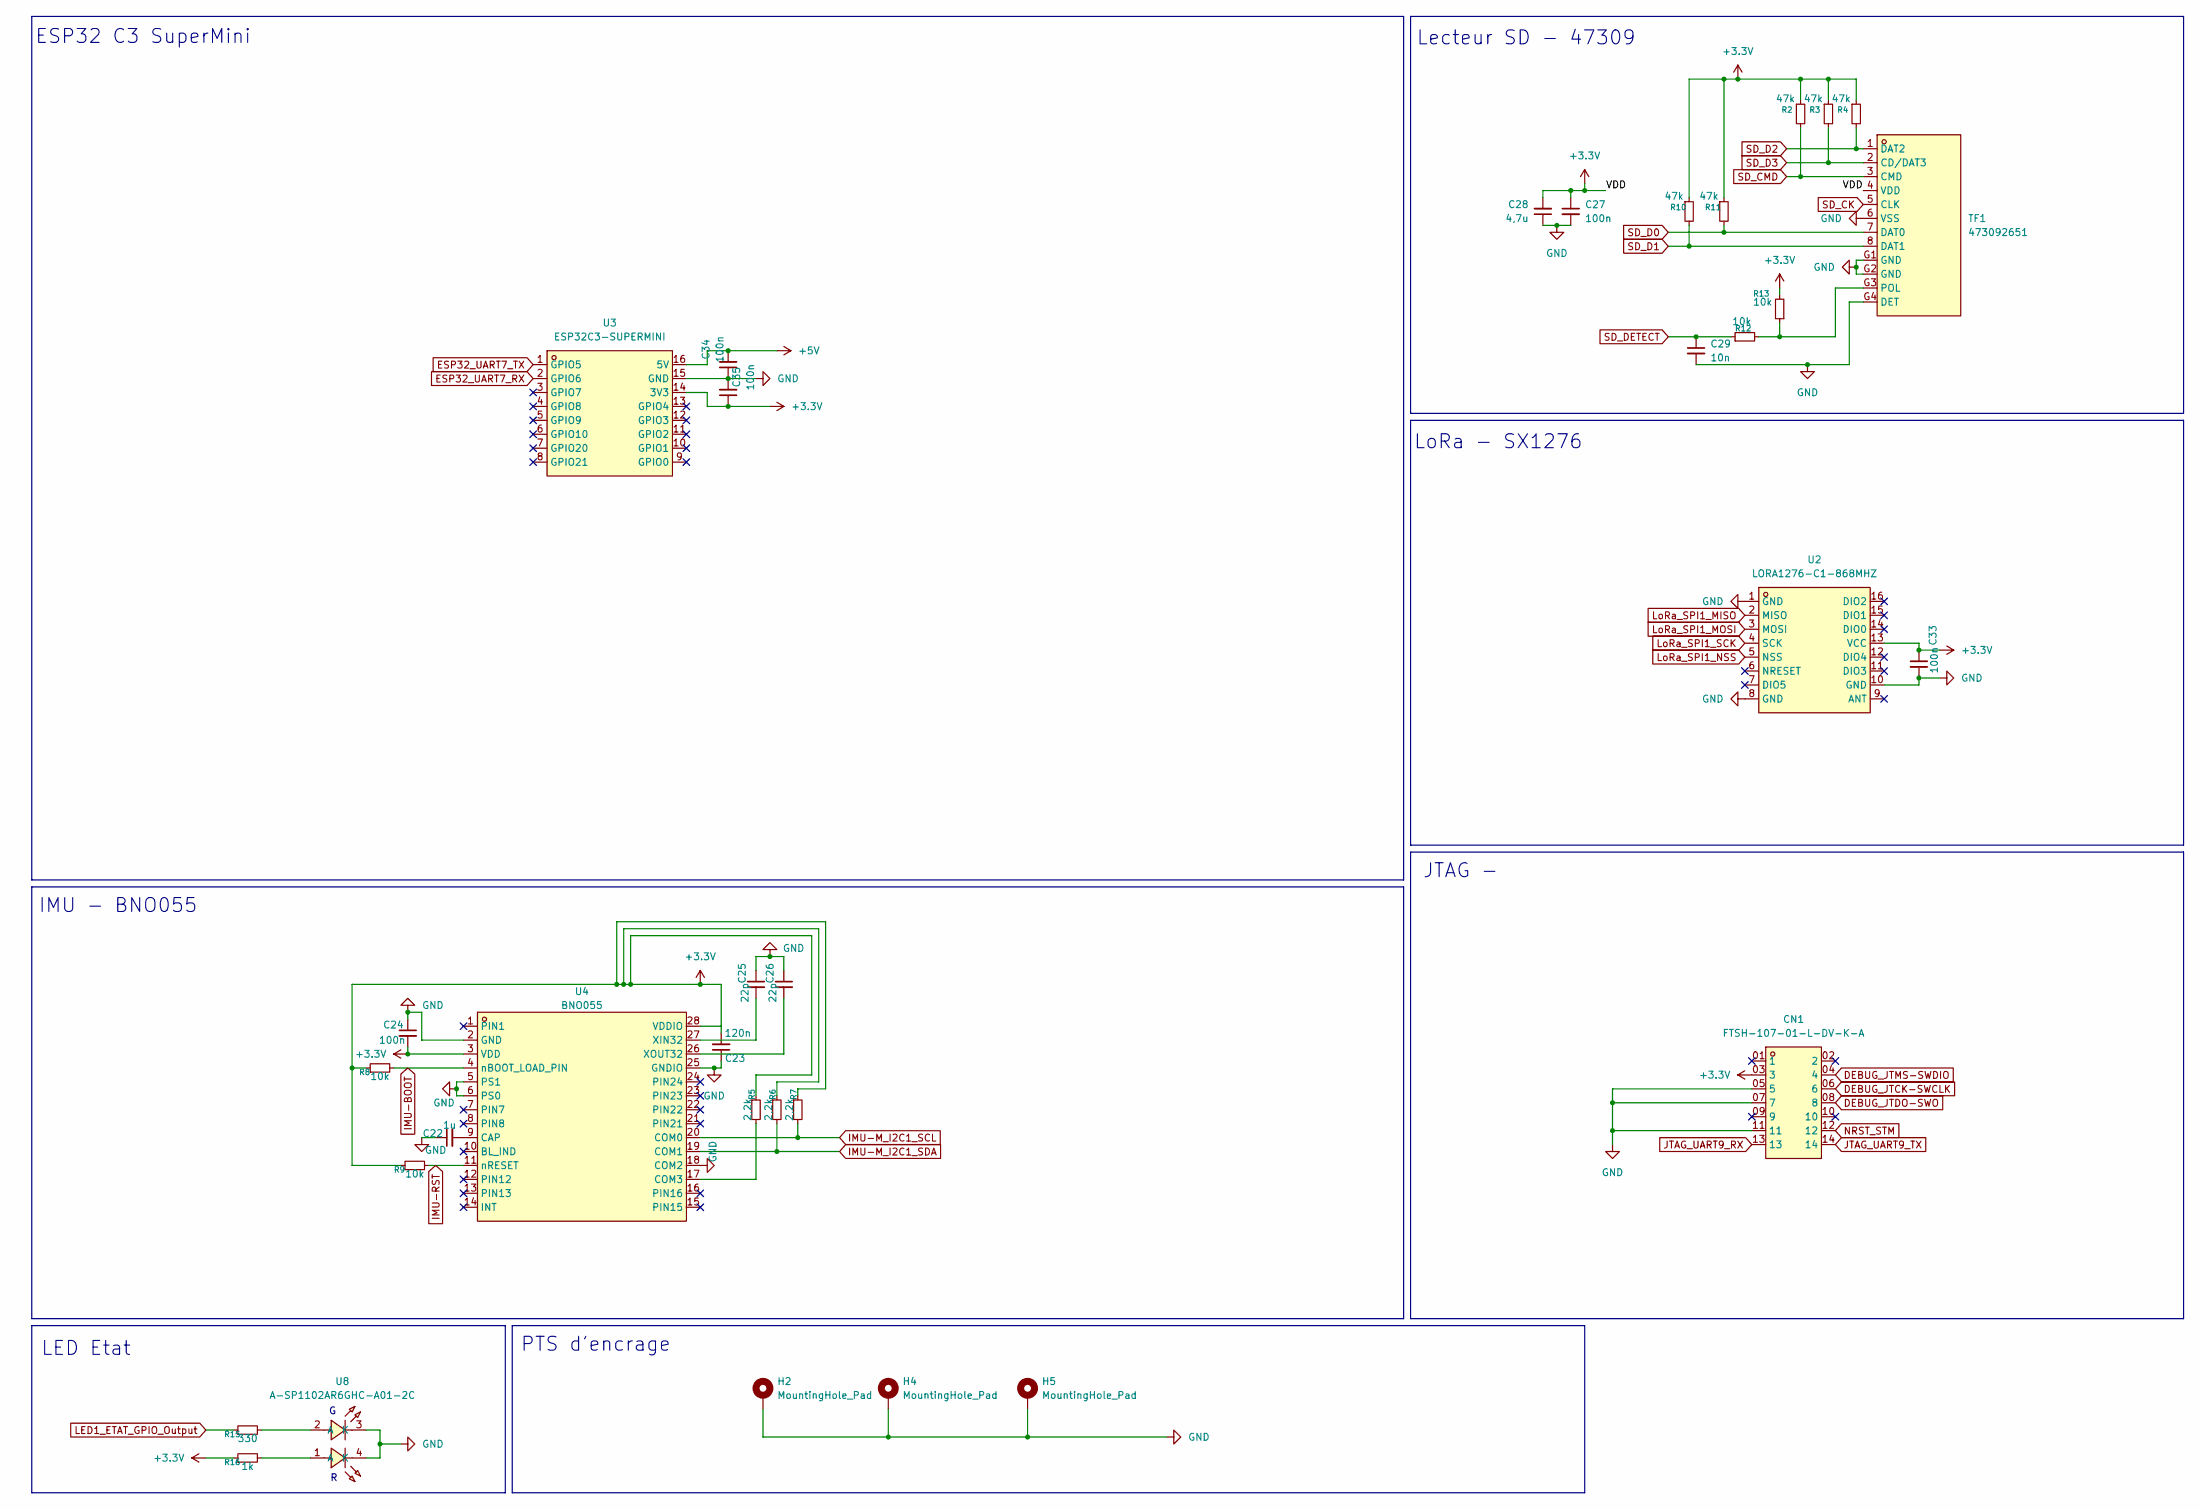
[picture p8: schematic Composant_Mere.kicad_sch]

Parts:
C22: 1u; C_0201_0603Metric; LCSC Part C52923
C23: 120n; C_0201_0603Metric; LCSC Part C18164575
C24, C27, C33, C34, C35: 100n; C_0201_0603Metric; LCSC Part C49062
C25, C26: 22p; C_0201_0603Metric; LCSC Part C76924
C28: 4,7u; C_0201_0603Metric; LCSC Part C19666
C29: 10n; C_0402_1005Metric; LCSC Part C15195
CN1: FTSH-107-01-L-DV-K-A; HDR-SMD_14P-P1.27_FTSH-107-01-L-DV-K-A; MPN FTSH-107-01-L-DV-K-A; LCSC Part C5563894
H2, H4, H5: MountingHole_Pad; MountingHole_3.2mm_M3_DIN965_Pad_TopBottom
R2, R3, R4, R10, R11: 47k; R_0201_0603Metric; LCSC Part C100140
R5, R6, R7: 2,2k; R_0201_0603Metric; LCSC Part C19420386
R8, R9, R12, R13: 10k; R_0201_0603Metric; LCSC Part C100126
R15: 330; R_0201_0603Metric; LCSC Part 320833
R16: 1k; R_0201_0603Metric; LCSC Part C102683
TF1: 473092651; TF-SMD_47309-2285; MPN 473092651; LCSC Part C587826
U2: LORA1276-C1-868MHZ; COMM-SMD_LORA1276-C1-915MHZ; MPN lora1276-C1-868MHz; LCSC Part C3001532
U3: ESP32C3-SUPERMINI; COMM-SMD_16P-L22.5-W18.0-P2.54-TL; MPN ESP32C3-SuperMini; LCSC Part C9900147397
U4: BNO055; LGA-28_L5.2-W3.8-P0.50-BL; MPN BNO055; LCSC Part C93216
U8: A-SP1102AR6GHC-A01-2C; LED-SMD_4P-L3.0-W1.5_A-SP1102AR6GHC-A01-2C; MPN A-SP1102AR6GHC-A01-2C; LCSC Part C5160724

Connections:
DEBUG_JTCK-SWCLK: CN1.06 (6); also elsewhere on the board
DEBUG_JTDO-SWO: CN1.08 (8); also elsewhere on the board
DEBUG_JTMS-SWDIO: CN1.04 (4); also elsewhere on the board
ESP32_UART7_RX: U3.2 (GPIO6); also elsewhere on the board
ESP32_UART7_TX: U3.1 (GPIO5); also elsewhere on the board
IMU-BOOT: R8.2, U4.4 (nBOOT_LOAD_PIN)
IMU-M_I2C1_SCL: R7.2, U4.20 (COM0); also elsewhere on the board
IMU-M_I2C1_SDA: R6.2, U4.19 (COM1); also elsewhere on the board
IMU-RST: R9.2, U4.11 (nRESET)
JTAG_UART9_RX: CN1.13; also elsewhere on the board
JTAG_UART9_TX: CN1.14; also elsewhere on the board
LED1_ETAT_GPIO_Output: R15.1; also elsewhere on the board
LoRa_SPI1_MISO: U2.2 (MISO); also elsewhere on the board
LoRa_SPI1_MOSI: U2.3 (MOSI); also elsewhere on the board
LoRa_SPI1_NSS: U2.5 (NSS); also elsewhere on the board
LoRa_SPI1_SCK: U2.4 (SCK); also elsewhere on the board
NRST_STM: CN1.12; also elsewhere on the board
unnamed: R15.2, U8.2 (A)
unnamed: R16.2, U8.1 (A)
unnamed: R12.2, R13.1, TF1.G3 (POL)
unnamed: C22.2, U4.9 (CAP)
unnamed: R5.2, U4.17 (COM3)
unnamed: C25.2, U4.27 (XIN32)
unnamed: C26.2, U4.26 (XOUT32)
SD_CK: TF1.5 (CLK); also elsewhere on the board
SD_CMD: R2.2, TF1.3 (CMD); also elsewhere on the board
SD_D0: R11.2, TF1.7 (DAT0); also elsewhere on the board
SD_D1: R10.2, TF1.8 (DAT1); also elsewhere on the board
SD_D2: R4.2, TF1.1 (DAT2); also elsewhere on the board
SD_D3: R3.2, TF1.2 (CD/DAT3); also elsewhere on the board
SD_DETECT: C29.1, R12.1; also elsewhere on the board

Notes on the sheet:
IMU - BNO055
ESP32 C3 SuperMini
PTS d'encrage
LED Etat
JTAG -
LoRa - SX1276
Lecteur SD - 47309

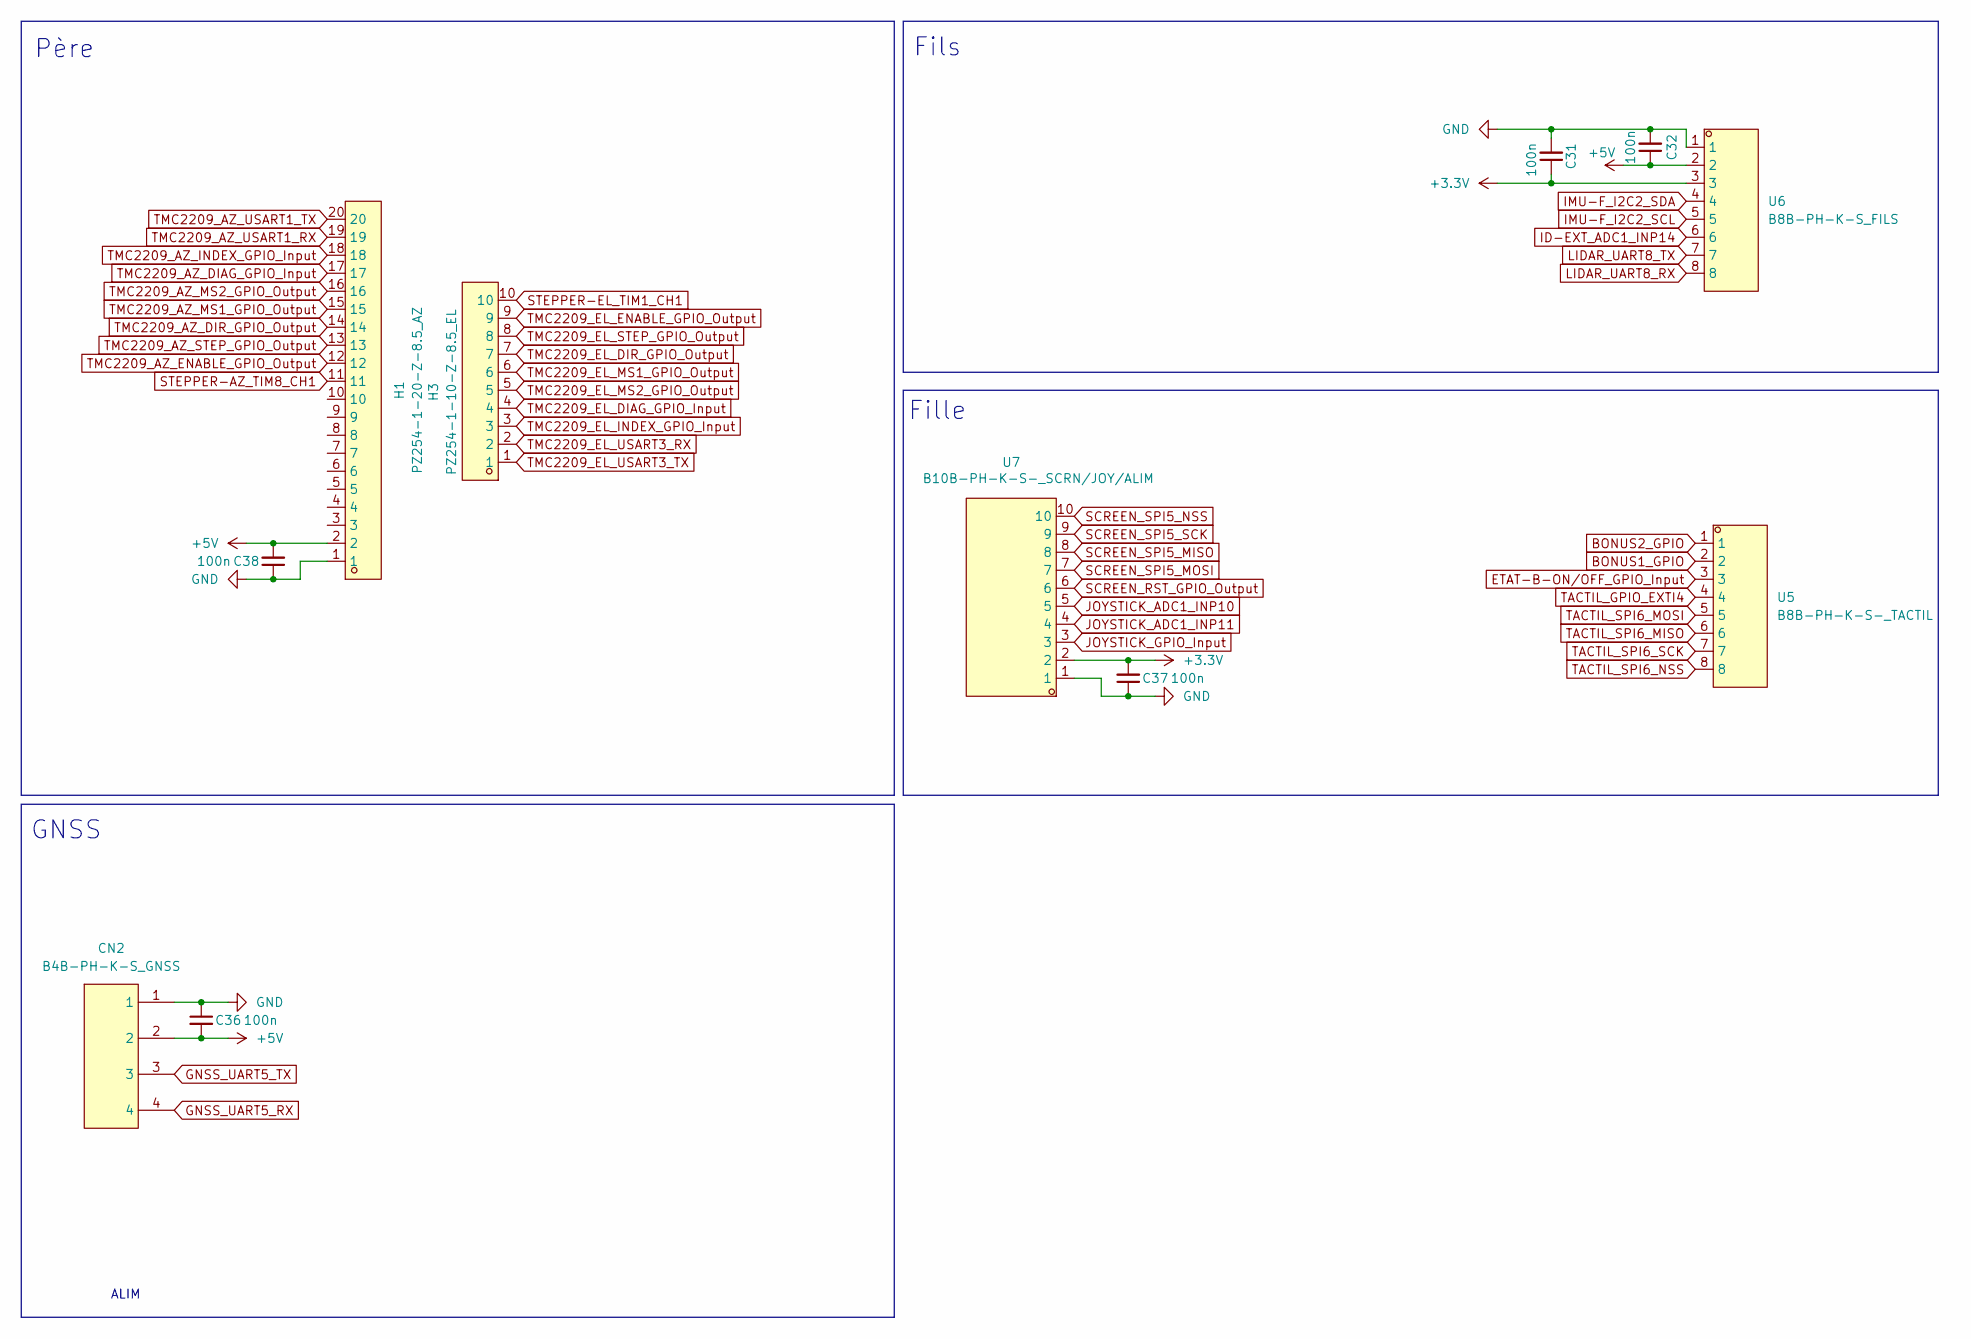
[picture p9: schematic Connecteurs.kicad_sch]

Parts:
C31, C32, C36, C37, C38: 100n; C_0201_0603Metric; LCSC Part C49062
CN2: B4B-PH-K-S_GNSS; CONN-TH_B4B-PH-K-S; MPN B4B-PH-K-S(LF)(SN); LCSC Part C131334
H1: PZ254-1-20-Z-8.5_AZ; HDR-TH_20P-P2.54-V-M; MPN PZ254-1-20-Z-8.5; LCSC Part C2894943
H3: PZ254-1-10-Z-8.5_EL; HDR-TH_10P-P2.54-V-M; MPN PZ254-1-10-Z-8.5; LCSC Part C2894933
U5: B8B-PH-K-S-_TACTIL; CONN-TH_B8B-PH-K-S-LF-SN; MPN B8B-PH-K-S(LF)(SN); LCSC Part C157974
U6: B8B-PH-K-S_FILS; CONN-TH_B8B-PH-K-S-LF-SN; MPN B8B-PH-K-S(LF)(SN); LCSC Part C157974
U7: B10B-PH-K-S-_SCRN/JOY/ALIM; CONN-TH_B10B-PH-K-S-LF-SN; MPN B10B-PH-K-S(LF)(SN); LCSC Part C158038

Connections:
BONUS1_GPIO: U5.2; also elsewhere on the board
BONUS2_GPIO: U5.1; also elsewhere on the board
ETAT-B-ON/OFF_GPIO_Input: U5.3; also elsewhere on the board
GNSS_UART5_RX: CN2.4; also elsewhere on the board
GNSS_UART5_TX: CN2.3; also elsewhere on the board
ID-EXT_ADC1_INP14: U6.6; also elsewhere on the board
IMU-F_I2C2_SCL: U6.5; also elsewhere on the board
IMU-F_I2C2_SDA: U6.4; also elsewhere on the board
JOYSTICK_ADC1_INP10: U7.5; also elsewhere on the board
JOYSTICK_ADC1_INP11: U7.4; also elsewhere on the board
JOYSTICK_GPIO_Input: U7.3; also elsewhere on the board
LIDAR_UART8_RX: U6.8; also elsewhere on the board
LIDAR_UART8_TX: U6.7; also elsewhere on the board
SCREEN_RST_GPIO_Output: U7.6; also elsewhere on the board
SCREEN_SPI5_MISO: U7.8; also elsewhere on the board
SCREEN_SPI5_MOSI: U7.7; also elsewhere on the board
SCREEN_SPI5_NSS: U7.10; also elsewhere on the board
SCREEN_SPI5_SCK: U7.9; also elsewhere on the board
STEPPER-AZ_TIM8_CH1: H1.11; also elsewhere on the board
STEPPER-EL_TIM1_CH1: H3.10; also elsewhere on the board
TACTIL_GPIO_EXTI4: U5.4; also elsewhere on the board
TACTIL_SPI6_MISO: U5.6; also elsewhere on the board
TACTIL_SPI6_MOSI: U5.5; also elsewhere on the board
TACTIL_SPI6_NSS: U5.8; also elsewhere on the board
TACTIL_SPI6_SCK: U5.7; also elsewhere on the board
TMC2209_AZ_DIAG_GPIO_Input: H1.17; also elsewhere on the board
TMC2209_AZ_DIR_GPIO_Output: H1.14; also elsewhere on the board
TMC2209_AZ_ENABLE_GPIO_Output: H1.12; also elsewhere on the board
TMC2209_AZ_INDEX_GPIO_Input: H1.18; also elsewhere on the board
TMC2209_AZ_MS1_GPIO_Output: H1.15; also elsewhere on the board
TMC2209_AZ_MS2_GPIO_Output: H1.16; also elsewhere on the board
TMC2209_AZ_STEP_GPIO_Output: H1.13; also elsewhere on the board
TMC2209_AZ_USART1_RX: H1.19; also elsewhere on the board
TMC2209_AZ_USART1_TX: H1.20; also elsewhere on the board
TMC2209_EL_DIAG_GPIO_Input: H3.4; also elsewhere on the board
TMC2209_EL_DIR_GPIO_Output: H3.7; also elsewhere on the board
TMC2209_EL_ENABLE_GPIO_Output: H3.9; also elsewhere on the board
TMC2209_EL_INDEX_GPIO_Input: H3.3; also elsewhere on the board
TMC2209_EL_MS1_GPIO_Output: H3.6; also elsewhere on the board
TMC2209_EL_MS2_GPIO_Output: H3.5; also elsewhere on the board
TMC2209_EL_STEP_GPIO_Output: H3.8; also elsewhere on the board
TMC2209_EL_USART3_RX: H3.2; also elsewhere on the board
TMC2209_EL_USART3_TX: H3.1; also elsewhere on the board

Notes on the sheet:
ALIM
Fils
Fille
GNSS
Père

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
Board: 2 copper layers, 73 parts (0 on the bottom side), 80 nets, no tracks yet.

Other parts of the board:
R6#2, R7#2: 2,2k; R_0201_0603Metric

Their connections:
IMU-M_I2C1_SCL: R7#2.2; also elsewhere on the board
IMU-M_I2C1_SDA: R6#2.2; also elsewhere on the board

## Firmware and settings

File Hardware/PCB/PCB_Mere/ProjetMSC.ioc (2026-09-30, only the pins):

Mcu.UserName=STM32H723ZGTx
PA13(JTMS/SWDIO).GPIO_Label=DEBUG_JTMS-SWDIO
PA13(JTMS/SWDIO).Signal=DEBUG_JTMS-SWDIO
PA14(JTCK/SWCLK).GPIO_Label=DEBUG_JTCK-SWCLK
PA14(JTCK/SWCLK).Signal=DEBUG_JTCK-SWCLK
PA2.GPIO_Label=ID-EXT_ADC1_INP14
PA2.Signal=ADCx_INP14
PB10.GPIO_Label=TMC2209_EL_INDEX_GPIO_Input
PB10.Signal=GPIO_Input
PB11.GPIO_Label=TMC2209_EL_USART3_RX
PB11.Signal=USART3_RX
PB12.GPIO_Label=GNSS_UART5_RX
PB12.Signal=UART5_RX
PB13.GPIO_Label=GNSS_UART5_TX
PB13.Signal=UART5_TX
PB14.GPIO_Label=TMC2209_AZ_USART1_TX
PB14.Signal=USART1_TX
PB15.GPIO_Label=TMC2209_AZ_USART1_RX
PB15.Signal=USART1_RX
PB3(JTDO/TRACESWO).GPIO_Label=DEBUG_JTDO-SWO
PB3(JTDO/TRACESWO).Signal=DEBUG_JTDO-SWO
PB6.GPIO_Label=IMU-M_I2C1_SCL
PB6.Signal=I2C1_SCL
PB7.GPIO_Label=IMU-M_I2C1_SDA
PB7.Signal=I2C1_SDA
PC0.GPIO_Label=JOYSTICK_ADC1_INP10
PC0.Signal=ADCx_INP10
PC1.GPIO_Label=JOYSTICK_ADC1_INP11
PC1.Signal=ADCx_INP11
PC10.GPIO_Label=SD_D2
PC10.Signal=SDMMC1_D2
PC11.GPIO_Label=SD_D3
PC11.Signal=SDMMC1_D3
PC12.GPIO_Label=SD_CK
PC12.Signal=SDMMC1_CK
PC2_C.GPIO_Label=JOYSTICK_GPIO_Input
PC2_C.Signal=GPIO_Input
PC3_C.GPIO_Label=ETAT-B-ON/OFF_GPIO_Input
PC3_C.Signal=GPIO_Input
PC6.GPIO_Label=STEPPER-AZ_TIM8_CH1
PC6.Signal=S_TIM8_CH1
PC7.GPIO_Label=SD_DETECT
PC7.Signal=GPIO_Input
PC8.GPIO_Label=SD_D0
PC8.Signal=SDMMC1_D0
PC9.GPIO_Label=SD_D1
PC9.Signal=SDMMC1_D1
PD11.GPIO_Label=LED2_DEBUG_GPIO_Output
PD11.Signal=GPIO_Output
PD12.GPIO_Label=LED1_ETAT_GPIO_Output
PD12.Signal=GPIO_Output
PD15.GPIO_Label=TMC2209_AZ_INDEX_GPIO_Input
PD15.Signal=GPIO_Input
PD2.GPIO_Label=SD_CMD
PD2.Signal=SDMMC1_CMD
PD7.GPIO_Label=LoRa_SPI1_MOSI
PD7.Signal=SPI1_MOSI
PD8.GPIO_Label=TMC2209_EL_USART3_TX
PD8.Signal=USART3_TX
PE0.GPIO_Label=LIDAR_UART8_RX
PE0.Signal=UART8_RX
PE1.GPIO_Label=LIDAR_UART8_TX
PE1.Signal=UART8_TX
PE10.GPIO_Label=TMC2209_EL_ENABLE_GPIO_Output
PE10.Signal=GPIO_Output
PE11.GPIO_Label=TMC2209_EL_STEP_GPIO_Output
PE11.Signal=GPIO_Output
PE12.GPIO_Label=TMC2209_EL_DIR_GPIO_Output
PE12.Signal=GPIO_Output
PE13.GPIO_Label=TMC2209_EL_MS1_GPIO_Output
PE13.Signal=GPIO_Output
PE14.GPIO_Label=TMC2209_EL_MS2_GPIO_IOutput
PE14.Signal=GPIO_Output
PE15.GPIO_Label=TMC2209_EL_DIAG_GPIO_Input
PE15.Signal=GPIO_Input
PE7.GPIO_Label=ESP32_UART7_RX
PE7.Signal=UART7_RX
PE8.GPIO_Label=ESP32_UART7_TX
PE8.Signal=UART7_TX
PE9.GPIO_Label=STEPPER-EL_TIM1_CH1
PE9.Signal=S_TIM1_CH1
PF0.GPIO_Label=IMU-F_I2C2_SDA
PF0.Signal=I2C2_SDA
PF1.GPIO_Label=IMU-F_I2C2_SCL
PF1.Signal=I2C2_SCL
PF6.GPIO_Label=SCREEN_SPI5_NSS
PF6.Signal=SPI5_NSS
PF7.GPIO_Label=SCREEN_SPI5_SCK
PF7.Signal=SPI5_SCK
PF8.GPIO_Label=SCREEN_SPI5_MISO
PF8.Signal=SPI5_MISO
PF9.GPIO_Label=SCREEN_SPI5_MOSI
PF9.Signal=SPI5_MOSI
PG0.GPIO_Label=JTAG_UART9_RX
PG0.Signal=UART9_RX
PG1.GPIO_Label=JTAG_UART9_TX
PG1.Signal=UART9_TX
PG10.GPIO_Label=LoRa_SPI1_NSS
PG10.Signal=SPI1_NSS
PG11.GPIO_Label=LoRa_SPI1_SCK
PG11.Signal=SPI1_SCK
PG2.GPIO_Label=TMC2209_AZ_DIAG_GPIO_Input
PG2.Signal=GPIO_Input
PG3.GPIO_Label=TMC2209_AZ_MS2_GPIO_Output
PG3.Signal=GPIO_Output
PG4.GPIO_Label=TMC2209_AZ_MS1_GPIO_Output
PG4.Signal=GPIO_Output
PG5.GPIO_Label=TMC2209_AZ_DIR_GPIO_Output
PG5.Signal=GPIO_Output
PG6.GPIO_Label=TMC2209_AZ_STEP_GPIO_Output
PG6.Signal=GPIO_Output
PG7.GPIO_Label=TMC2209_AZ_ENABLE_GPIO_Output
PG7.Signal=GPIO_Output
PG9.GPIO_Label=LoRa_SPI1_MISO
PG9.Signal=SPI1_MISO

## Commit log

2026-09-21 Ajout début de l'pplication
2026-09-22 Ajout des CR
2026-09-28 ajout cahier des charges application
2026-09-30 MAJ cahier des charges application
2026-10-06 Ajout des librairies
2026-10-08 push du kicad
    [Composant_Mere.kicad_sch, Connecteurs.kicad_sch, PCB_Mere_V1.kicad_pcb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]
2026-10-09 Dernière version Schématique
    [Composant_Mere.kicad_sch, Connecteurs.kicad_sch, PCB_Mere_V1.kicad_pcb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]
2026-10-09 Nouvelles empreintes de mounting holes et plusieurs court circuits retirés du schematic
    [Composant_Mere.kicad_sch, Connecteurs.kicad_sch, PCB_Mere_V1.kicad_pcb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]
2026-10-12 avancement schematic fils
2026-10-18 mise à jour PCB père
2026-10-19 Push PCB_Mère avancement routage
2026-10-19 Finalisation de la PCB_Mere, need vérification
2026-10-21 last version + Ajout du PCB Fils FINI?
2026-10-23 pcb père quasi fini
2026-10-23 Restauration de l'application (Parties 1 à 4.2) perdue lors d'un reset vers origin/main
    Un git reset avait ramené la branche sur origin/main, qui n'avait jamais reçu
    le travail fait depuis le début du tuto (resté seulement dans le commit local
    d168844). Fichiers restaurés depuis ce commit : astro.py, ciel/urls.py,
    appareil/services.py, appareil/urls.py, le simulateur, toutes les migrations,
    le CSS/JS/template de la carte, et le vendoring d3-celestial.
    Au passage : retrait de donnees_skyfield/ (de421.bsp, hip_main.dat) du suivi
    Git, ces fichiers téléchargés automatiquement par Skyfield n'ayant pas leur
    place dans le dépôt (le .gitignore les exclut de nouveau).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
2026-10-23 Contenu partagé : un fichier par astre, import et export, crédits des images
2026-10-29 Partie 5 : code de pilotage
2026-10-29 Inverse le sens vertical du glissement sur la carte
2026-10-29 Journalise les Parties 5 et 6.1 dans Tuto_Django
2026-10-29 Partie 6 : trajectoire 48 h, ISS (TLE + SGP4), position GPS de l'appareil
2026-10-29 Journalise la Partie 6 (6.1+6.2) dans Tuto_Django
2026-10-29 Partie 6.4 : partager la position du navigateur ; rattrape la 6.3 et les fichiers de la Partie 7
2026-10-29 Réinverse le sens vertical du glissement (écrasé par un remplacement complet de carte.js)
2026-10-29 Journalise la Partie 7 dans Tuto_Django (code déjà en place) ; importe le correctif Lune en base
2026-10-29 Partie 8 : fiche complétée, événements principaux, sources en temps réel ; réintègre la 6.4
    Le remplacement complet des fichiers ciel/ par l'archive de la Partie 8 avait à nouveau écrasé
    la position partagée par le navigateur (Partie 6.4, backend ciel/views.py + ciel/urls.py déjà
    cassé en pointant vers une vue disparue) et l'inversion du glisser vertical (déjà perdue une
    fois). Les deux sont réappliquées ici.
2026-10-29 Journalise la Partie 8 dans Tuto_Django
2026-10-29 Partie 8.4 : cible personnalisée (appui long) et filtres des astres ; réintègre la 6.4 (3e fois)
2026-10-29 Journalise la Partie 8.4 dans Tuto_Django
2026-10-30 Journalise les Parties 8.5 et 9 dans Tuto_Django
2026-10-30 Partie 10 : 16 fiches vérifiées, Soleil et ciel profond, images NASA
    Corrige au passage l'URL de l'image de la Lune dans images_sources.json : NASA a retiré le
    segment /jpeg/ du chemin (404 sur l'ancienne URL, 200 sur la nouvelle), même page et crédit.
2026-10-30 Journalise la Partie 10 dans Tuto_Django
2026-10-30 Journalise la Partie 10 bis dans Tuto_Django
2026-10-30 Journalise la Partie 14.1 dans Tuto_Django
2026-10-30 Partie 14.1 bis : calques sans doublon, horaires de la visite guidee, historique du bras
2026-10-30 Journalise la Partie 14.1 bis dans Tuto_Django
2026-11-09 ESP32 communication établie
2026-11-09 Journalise la Partie 10 ter (catalogue automatique) dans Tuto_Django
